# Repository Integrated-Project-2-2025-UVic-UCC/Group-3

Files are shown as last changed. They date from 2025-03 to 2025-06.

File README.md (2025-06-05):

# Autonomous Seeding Quadcopter

This repository contains all the information related to the development of an **autonomous seeding quadcopter**. It also includes everything needed to fully replicate the project.



## 🌱 Motivation

Modern agriculture faces significant challenges, including rising food demand, labor shortages, and the need to improve resource efficiency. Traditional planting methods—whether manual or reliant on heavy machinery—can be costly and inefficient. Labor and initial machinery investments can be very expensive compared to an autonomous drone, which is smaller, cheaper to purchase, and doesn’t require a human operator.

In recent years, automation and technology have started transforming the agricultural sector. Drones have proven useful for crop monitoring, spraying, and data collection. However, **automated drone-based seeding** is still in its early stages of development, presenting a unique opportunity to enhance precision agriculture and improve overall efficiency. This early-stage potential is what inspired us to pursue this project.

## 💪 How to Build

To fully replicate the project, follow these steps:

### 1️⃣ 3D Printing

First, 3D print all the components found in the _SolidWorks parts_ folder. Note that this process may take time, as there are several parts to produce.

### 2️⃣ PCB Building

Once all parts are printed, build the PCB according to the provided electrical schematic. Connect and solder all components, including ESC drivers. It's essential that the MPU6050 module is perfectly centered on the PCB frame.

### 3️⃣ Assembling the Drone

With all parts ready:

**1.** Attach the PCB to the _Bottom body_ (make sure all components are connected before assembly).

**2.** Assemble from bottom to top:

  - Attach the 4 _Leg_ to the _Bottom body_.
  - Attach the 4 _Arm_.
  - Close the structure with the _Upper body_.

At this point, the main structure is complete.

Then:

- Mount the brushless motors to each arm.
- Attach the _Upper battery support_ on top of the frame.

**Hopper Assembly**

1. Attach the servomotor to the _rotative valve cover_, and connect the _rotative valve_ to the servomotor.

2. Insert 4 inserts into the _hopper_.

3. Assemble the full hopper.

4. Attach it to the drone by inserting the two _hinge joints_ into their respective slots.

5. Secure the hopper using a through bolt.

6. Mount the distance sensor onto its support and glue it to the hopper wall.

### 4️⃣ Code Uploading

Once assembly is complete:

- Download the General_BT_Testing folder.
- Upload the program to your ESP32 microcontroller.

### ✅ Completion

If you've followed all the steps — congratulations! 🎉
Your **Autonomous Seeding Quadcopter** is now fully built and ready for testing using a **BLE-compatible device**.

Project by: _**Pau Porcuna, Guillem Català, Albert Huéscar & Álvaro Hernández**_

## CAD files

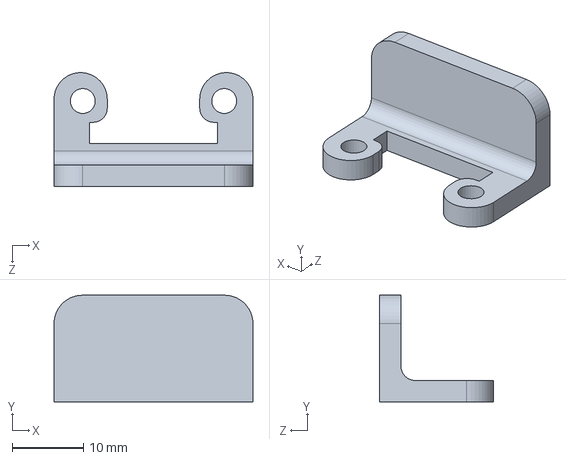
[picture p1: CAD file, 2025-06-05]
src/Structure/SolidWorks files/11 - Distance sensor support.SLDPRT
28.0 x 15.0 x 16.0 mm

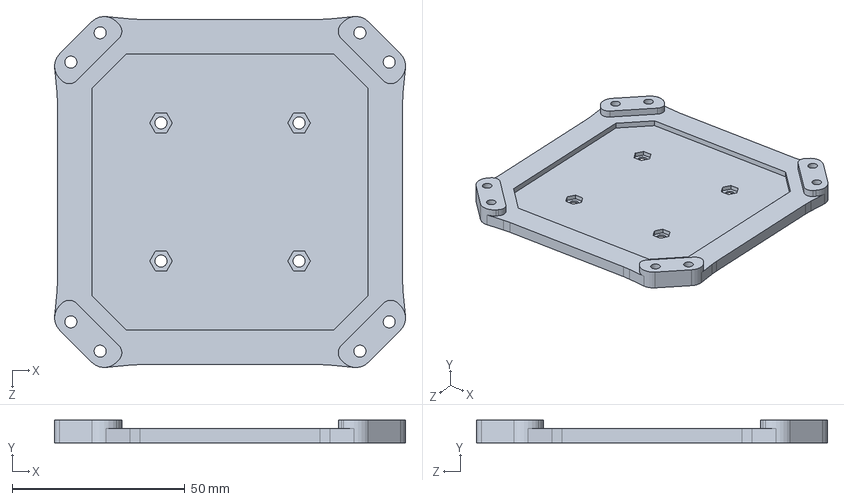
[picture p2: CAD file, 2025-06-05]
src/Structure/SolidWorks files/2 - Upper body.SLDPRT
101.7 x 6.60 x 101.7 mm

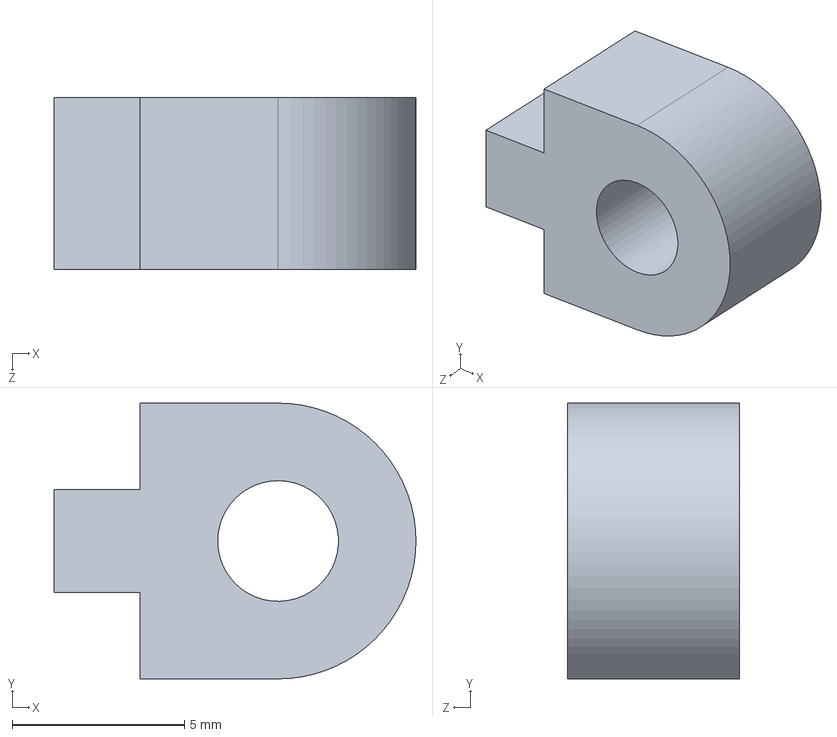
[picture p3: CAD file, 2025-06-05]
src/Structure/SolidWorks files/10 - Hinge joint.SLDPRT
10.5 x 8.00 x 5.00 mm

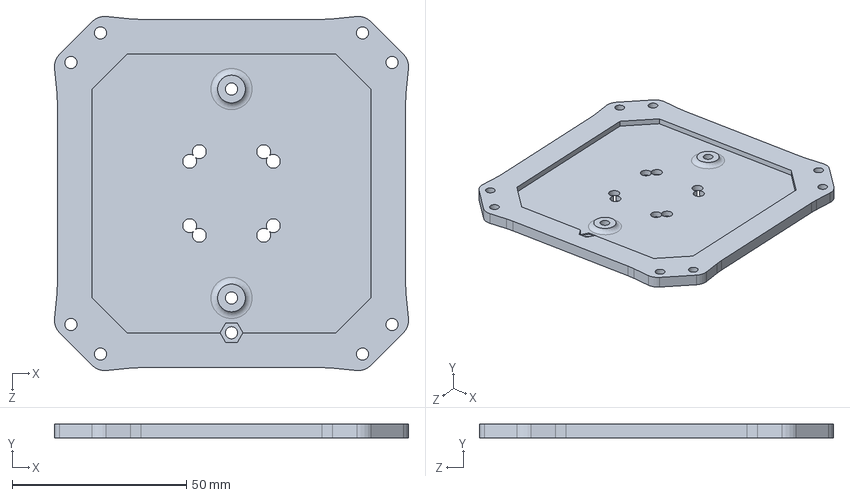
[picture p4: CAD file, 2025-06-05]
src/Structure/SolidWorks files/1 - Bottom body.SLDPRT
101.7 x 4.00 x 101.7 mm

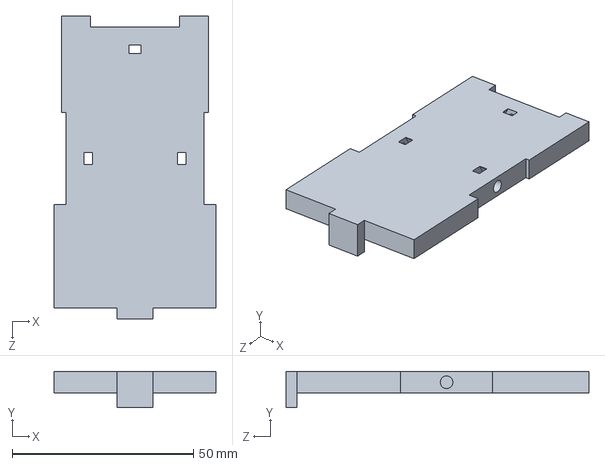
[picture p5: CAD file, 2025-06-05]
src/Structure/SolidWorks files/5 - Upper battery support.SLDPRT
44.6 x 10.0 x 83.6 mm

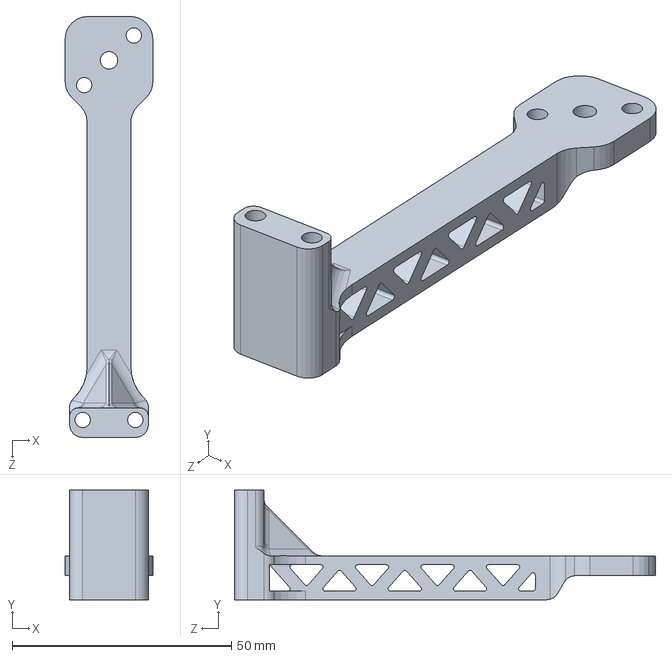
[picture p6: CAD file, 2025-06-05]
src/Structure/SolidWorks files/3 - Arm.SLDPRT
20.0 x 25.0 x 96.0 mm

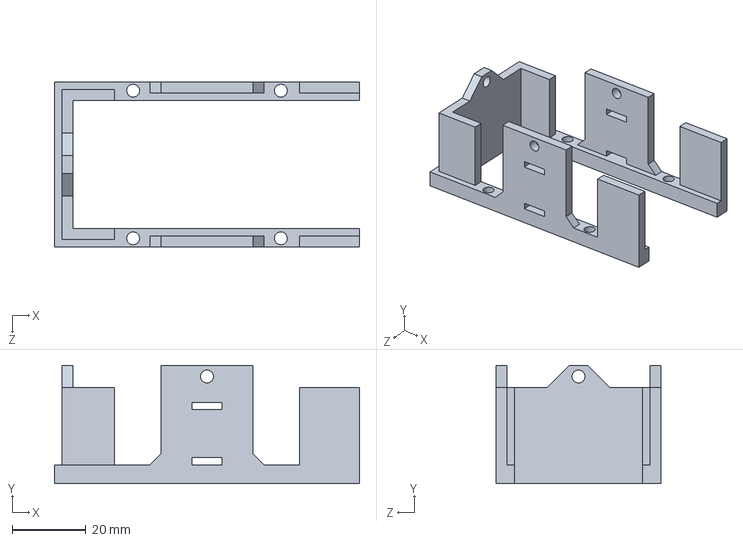
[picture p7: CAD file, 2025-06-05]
src/Structure/SolidWorks files/4 - Bottom battery support.SLDPRT
82.6 x 32.0 x 44.6 mm

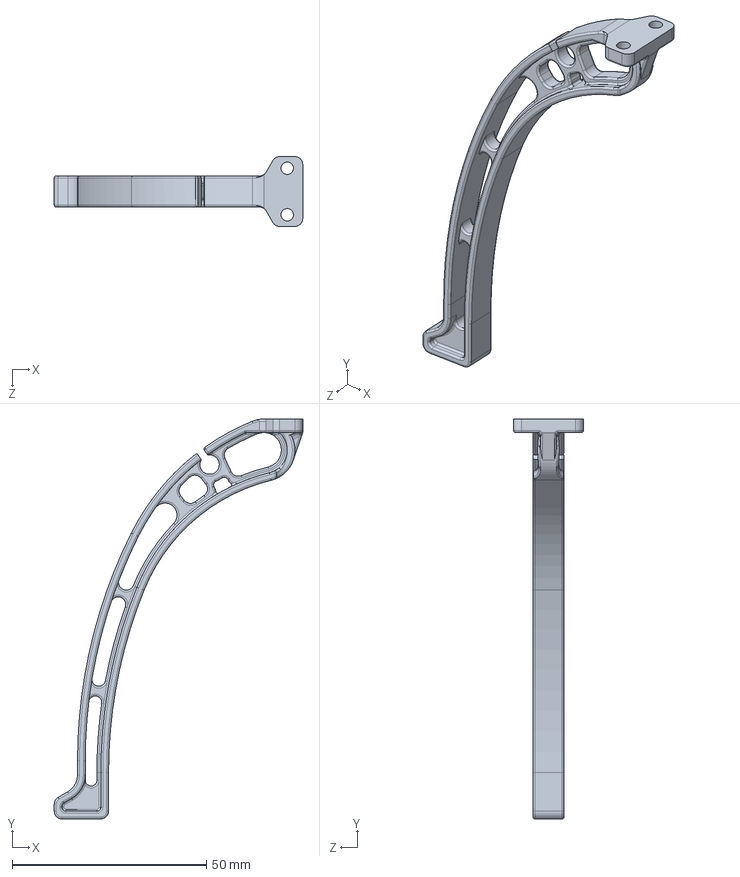
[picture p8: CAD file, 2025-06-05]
src/Structure/SolidWorks files/6 - Leg.SLDPRT
64.0 x 103.0 x 18.0 mm

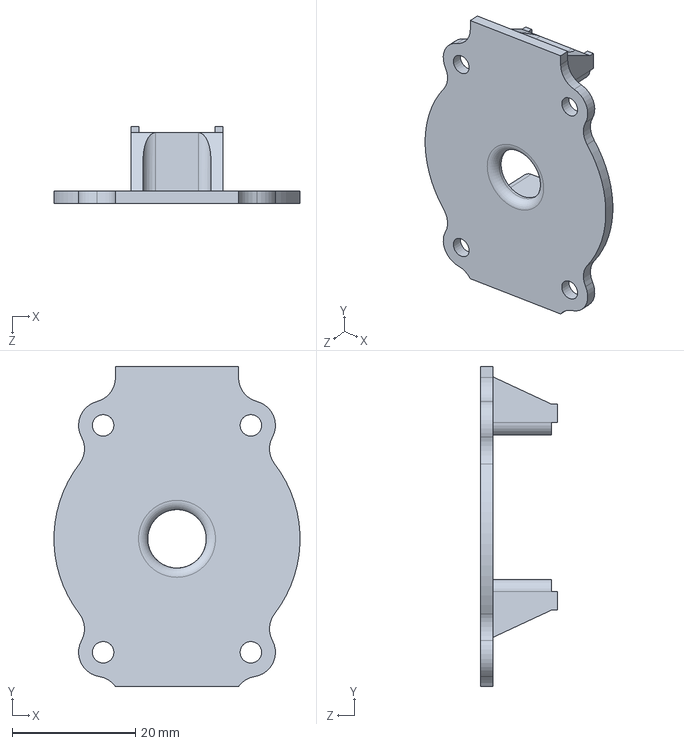
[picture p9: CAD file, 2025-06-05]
src/Structure/SolidWorks files/8 - Rotative valve cover.SLDPRT
40.0 x 52.0 x 12.5 mm

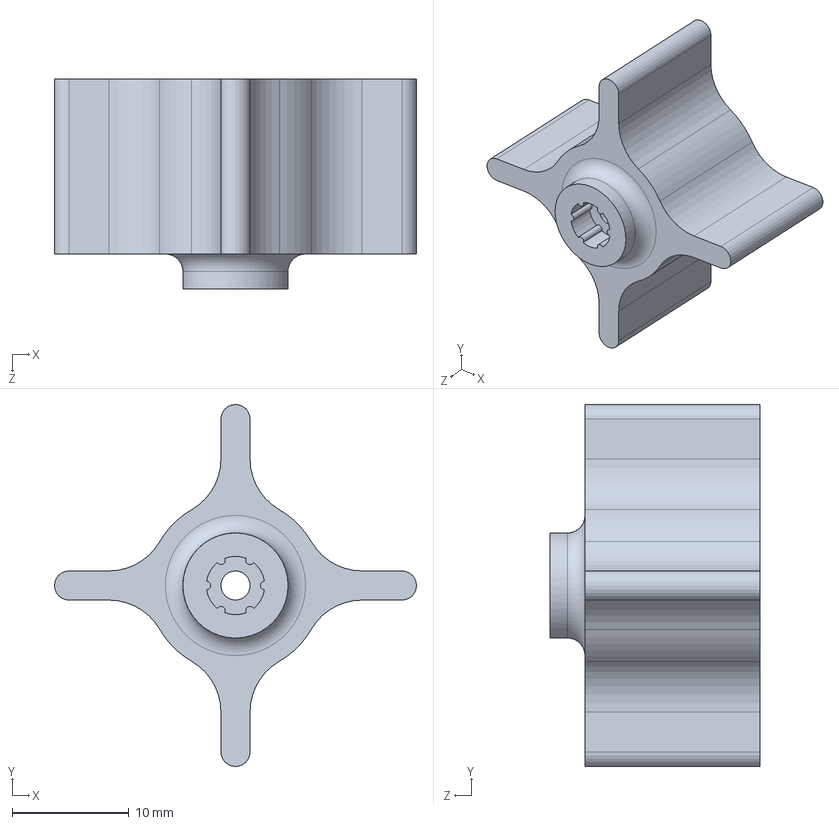
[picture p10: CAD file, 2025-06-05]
src/Structure/SolidWorks files/9 - Rotative valve.SLDPRT
31.0 x 31.0 x 18.0 mm

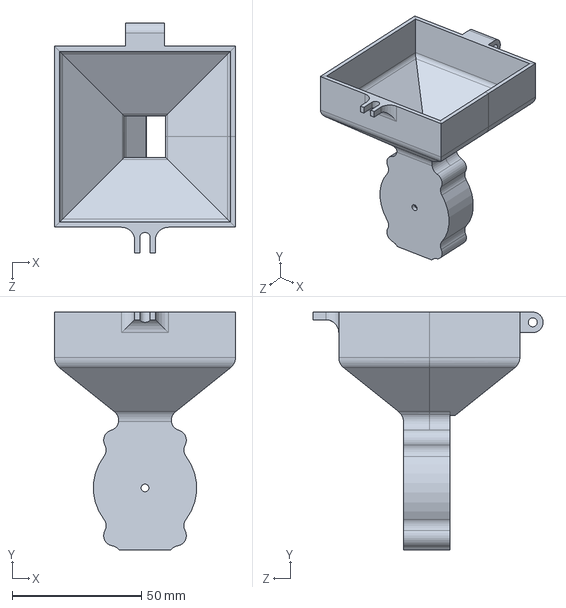
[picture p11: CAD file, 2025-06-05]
src/Structure/SolidWorks files/7 - Hopper + rotative valve enclosure.SLDPRT
70.0 x 92.0 x 89.0 mm

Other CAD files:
src/Structure/SolidWorks drawings/1 - Bottom body.SLDDRW
src/Structure/SolidWorks drawings/10 - Hinge joint.SLDDRW
src/Structure/SolidWorks drawings/11 - Distance sensor support.SLDDRW
src/Structure/SolidWorks drawings/2 - Upper body.SLDDRW
src/Structure/SolidWorks drawings/3 - Arm.SLDDRW
src/Structure/SolidWorks drawings/4 - Bottom battery support.SLDDRW
src/Structure/SolidWorks drawings/5 - Upper battery support.SLDDRW
src/Structure/SolidWorks drawings/6 - Leg.SLDDRW
src/Structure/SolidWorks drawings/7 - Hopper + rotative valve enclosure.SLDDRW
src/Structure/SolidWorks drawings/8 - Rotative valve cover.SLDDRW
src/Structure/SolidWorks drawings/9 - Rotative valve.SLDDRW

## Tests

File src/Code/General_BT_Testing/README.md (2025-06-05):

This files contain the main program to test the Drone via Bluetooth Low Energy. To upload the code to the ESP32 all this files have to be in a folder named "General_BT_Testing"

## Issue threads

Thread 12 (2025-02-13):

3D Doser Design

pauporcuna, 2025-02-13:
3D Model of the structure of the doser

- [ ] Desing of the main frame and mobile components of the doser
- [ ] Desing of the servo motor junction to the mobile components

Closed 2025-03-18.

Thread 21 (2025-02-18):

Stability and height PID control

guillem041, 2025-02-18:

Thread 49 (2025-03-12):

List of received material.

moises-garin, 2025-03-12:
This is the list of material received from UVic. Do not modify this list. If you detect any error, please contact the teachers.

- [ ] 1 x placa ESP32;
- [ ] 1 x mòdul Sensors GY-88 (giroscopi, aceleròmetre, bruixola i  sensor de presió/ temperatura);
- [ ] 1 x Mòdul GPS NEO 6M;
- [ ] 1 x Regulador LM 2596;
- [ ] 1 x bateria de Lipo 2200mAh;
- [ ] 1 x servo petit de 360º;
- [ ] 1 ESC de 18A + 1 motor brushless EMAX 2213;

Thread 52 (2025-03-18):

Soldering the components

Alvar05, 2025-03-18:
Soldering components to be able to make tests:

- [ ] GPS
- [ ] MPU6050 and Barometer
- [ ] ESC cables for testing

Closed 2025-03-25.

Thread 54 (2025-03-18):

Main components basic functions programming

Alvar05, 2025-03-18:
Program the basic functions to control the main sensors and actuators:

- [ ] MPU6050
- [ ] Barometer
- [ ] Brushless Motors

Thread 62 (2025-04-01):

Prototype finishing for stability control programming

Alvar05, 2025-04-01:
Finalization of first prototype to start programming and calibrating stability control modules

Closed 2025-04-25.

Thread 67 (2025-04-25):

1 axis stability PID programming

Alvar05, 2025-04-25:
Finish the code for 1 axis stabilization to start testing it

Closed 2025-05-06.

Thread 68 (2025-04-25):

1 axis stability control testing and PID values adjustment

Alvar05, 2025-04-25:
Testing of the stability control and making the adjustments to the PID constants to optimize the stabilizer

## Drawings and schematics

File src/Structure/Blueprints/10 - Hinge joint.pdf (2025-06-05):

F

4 | 3 | 2 | 1

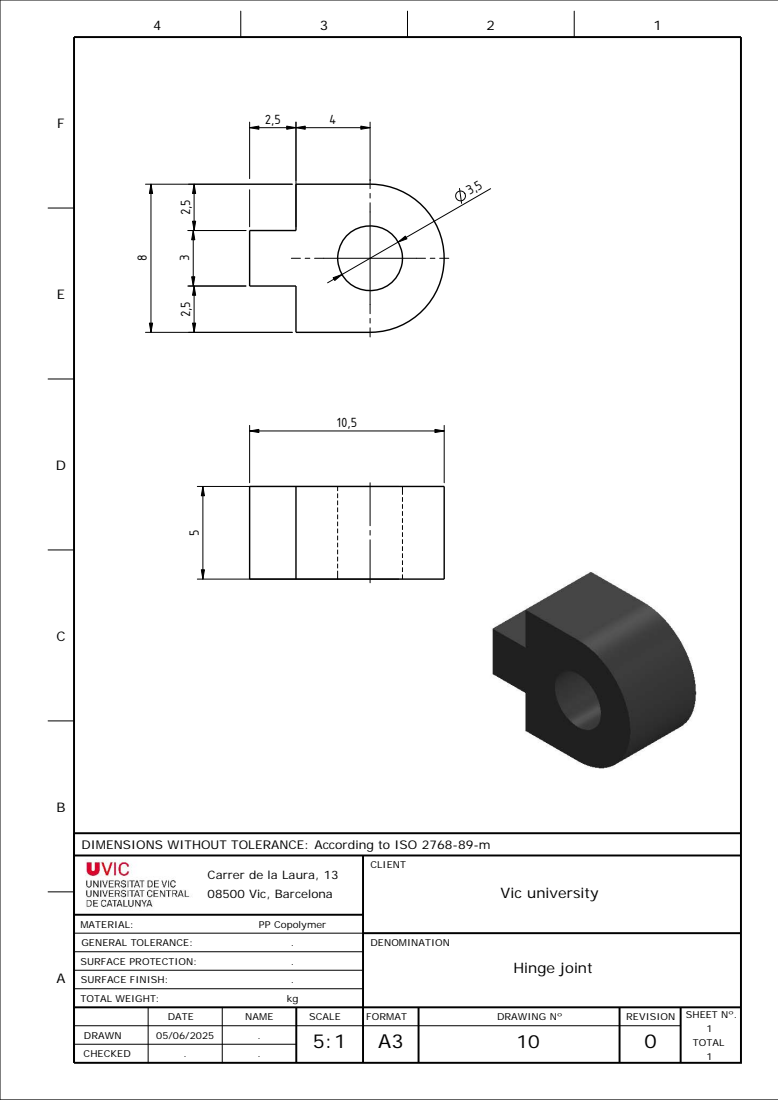
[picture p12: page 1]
REVISION; DENOMINATION; DATE; NAME; DRAWN; CHECKED; SCALE; FORMAT; DRAWING Nº; SHEET Nº.; TOTAL; SURFACE FINISH:; SURFACE PROTECTION:; GENERAL TOLERANCE:; MATERIAL:; TOTAL WEIGHT:; CLIENT; PP Copolymer; Hinge joint; Vic university

DIMENSIONS WITHOUT TOLERANCE: According to ISO 2768-89-m

Carrer de la Laura, 13
08500 Vic, Barcelona

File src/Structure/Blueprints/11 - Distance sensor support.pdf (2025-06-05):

2

F

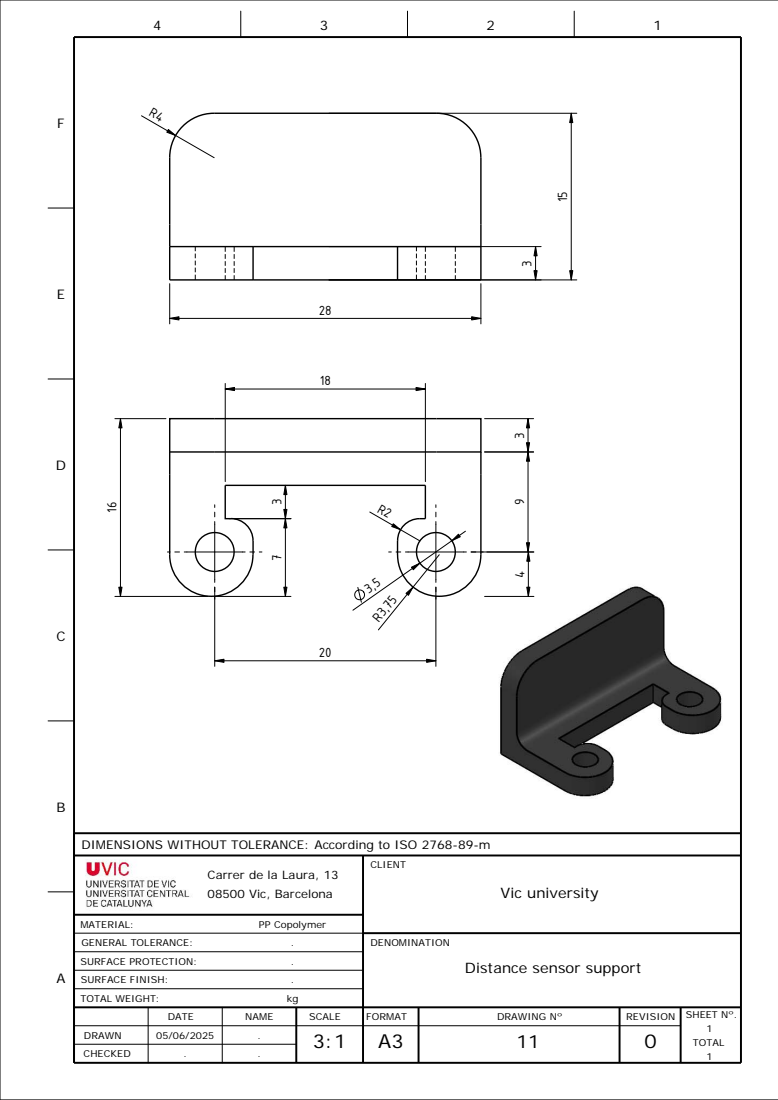
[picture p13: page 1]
DENOMINATION; CLIENT; TOTAL WEIGHT:; SURFACE PROTECTION:; PP Copolymer; GENERAL TOLERANCE:; SURFACE FINISH:; MATERIAL:; Vic university

DIMENSIONS WITHOUT TOLERANCE: According to ISO 2768-89-m

Carrer de la Laura, 13
08500 Vic, Barcelona

Distance sensor support

DATE | NAME | SCALE | FORMAT | DRAWING Nº | REVISION | SHEET Nº. 1 TOTAL 1

DRAWN | | . | 3:1 ⁰⁵/06/2025 | A3 | 11 | 0
CHECKED | . | .

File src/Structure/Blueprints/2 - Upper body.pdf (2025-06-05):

2 | 1

F

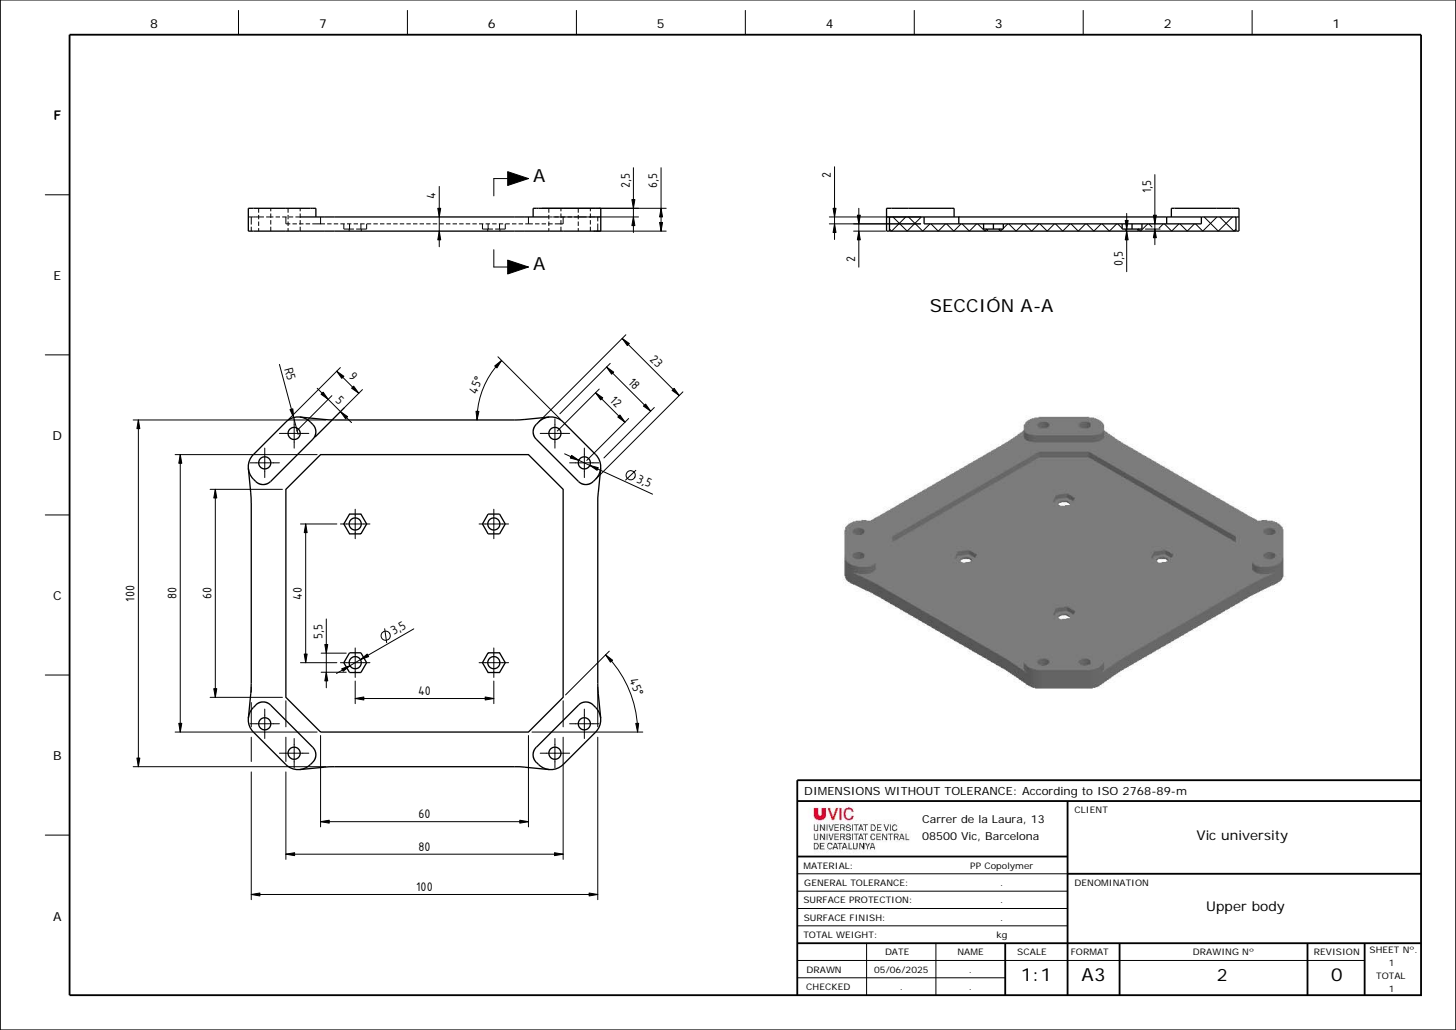
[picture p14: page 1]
PP Copolymer; CLIENT; TOTAL WEIGHT:; MATERIAL:; GENERAL TOLERANCE:; SURFACE PROTECTION:; SURFACE FINISH:; TOTAL; SCALE; FORMAT; DRAWING Nº; SHEET Nº.; CHECKED; DRAWN; DATE; NAME; DENOMINATION; REVISION; Upper body A; Vic university; SECCIÓN A-A

DIMENSIONS WITHOUT TOLERANCE: According to ISO 2768-89-m

Carrer de la Laura, 13
08500 Vic, Barcelona

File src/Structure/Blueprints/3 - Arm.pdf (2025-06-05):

4 | 3 | 2

F

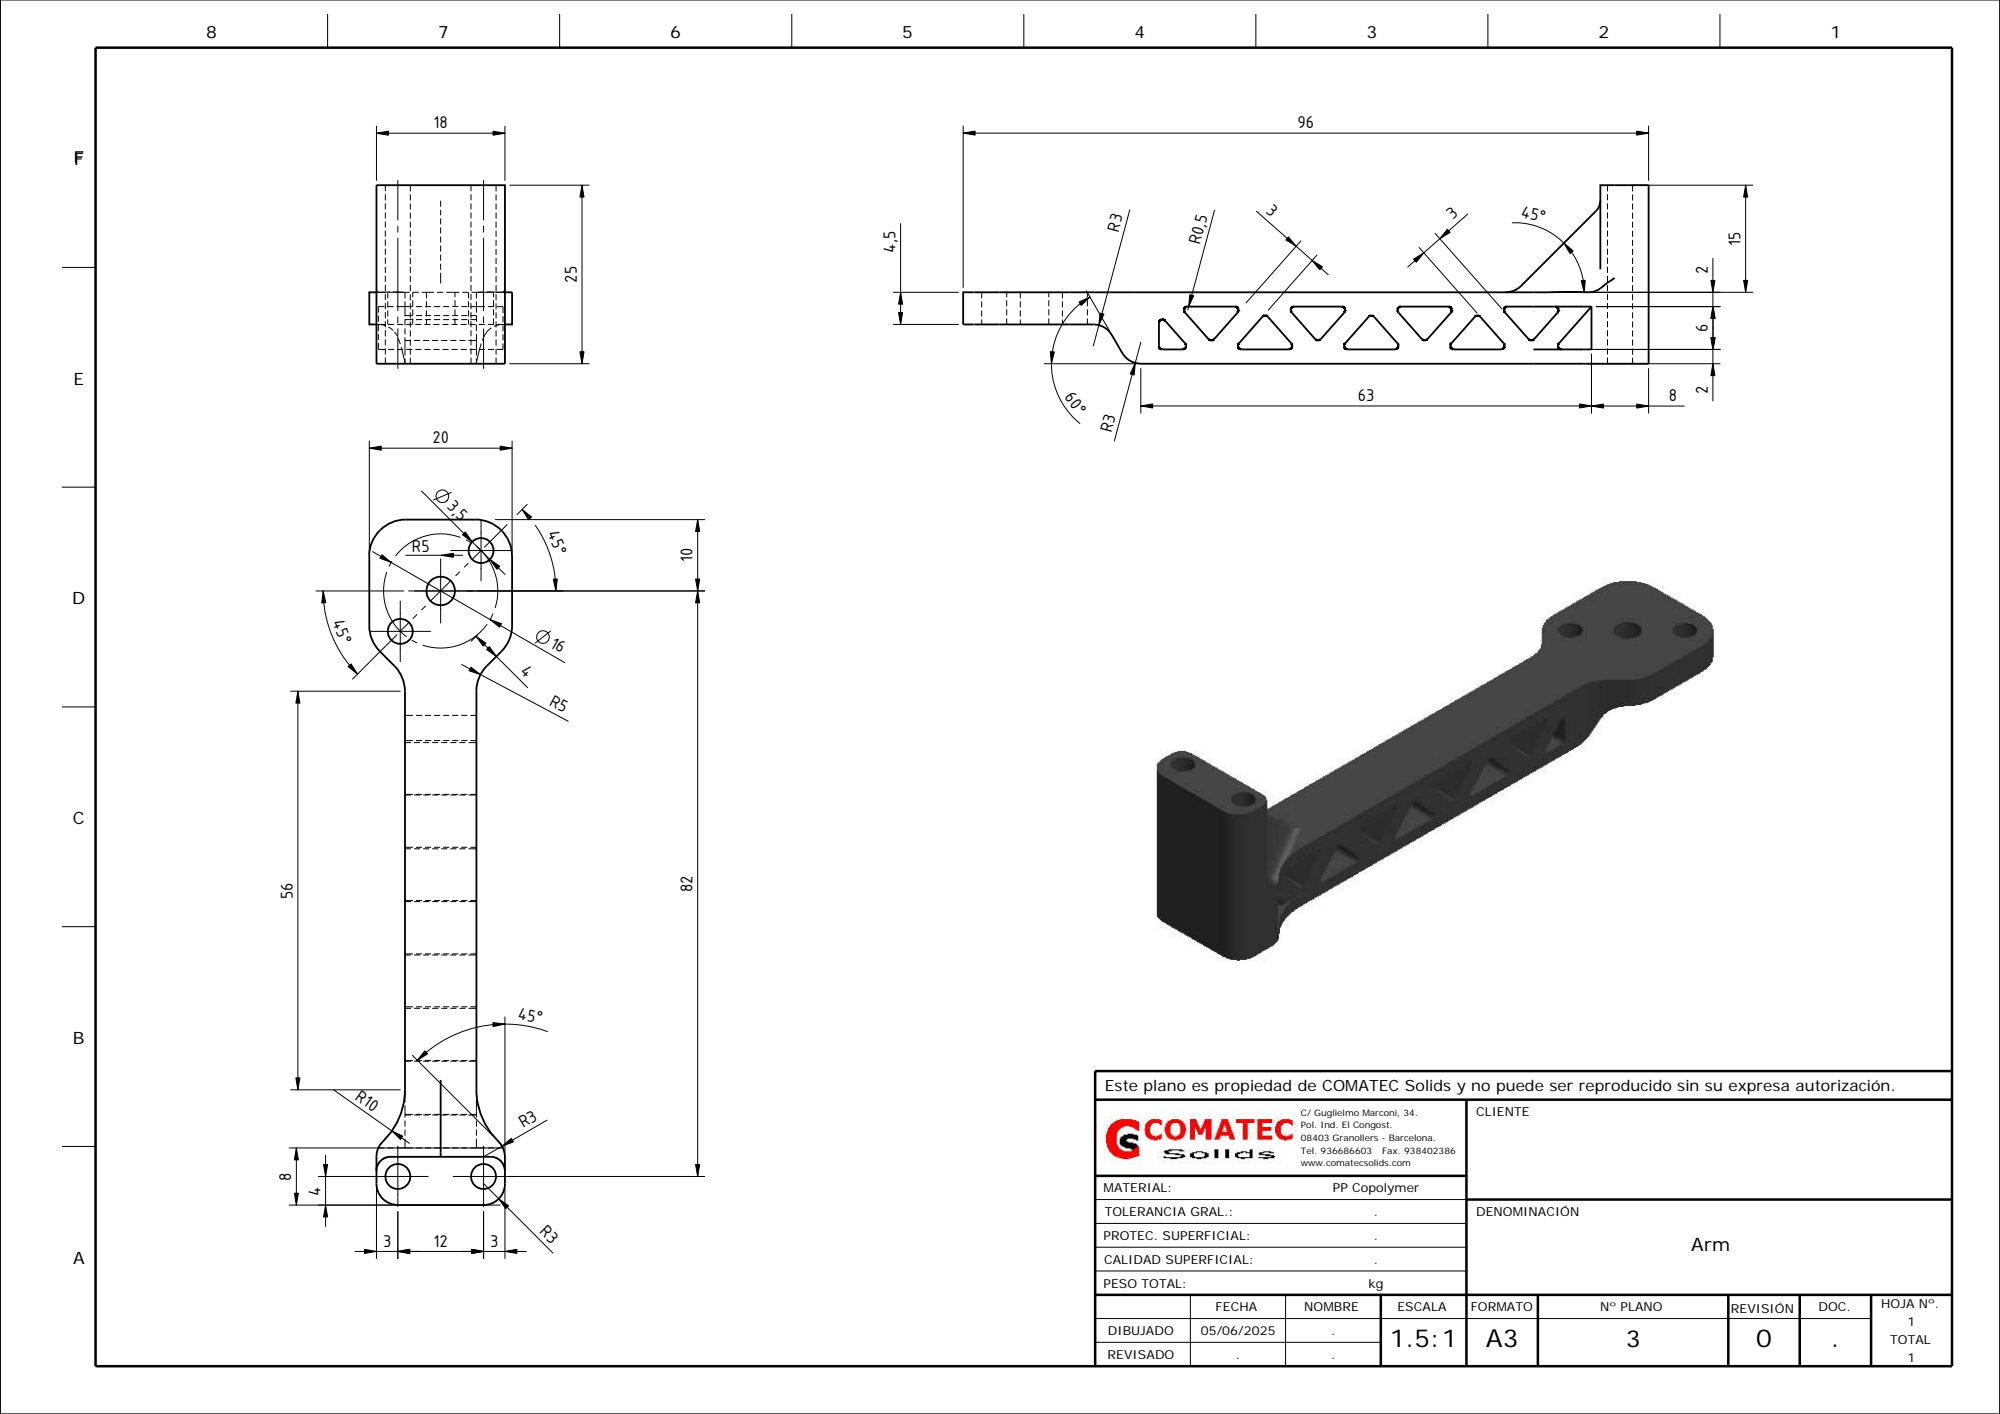
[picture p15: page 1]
CLIENTE; PESO TOTAL:; MATERIAL:; TOLERANCIA GRAL.:; PROTEC. SUPERFICIAL:; CALIDAD SUPERFICIAL:; DENOMINACIÓN; Fax. 938402386; Arm

Este plano es propiedad de COMATEC Solids y no puede ser reproducido sin su expresa autorización.

C/ Guglielmo Marconi, 34.
Pol. Ind. El Congost.
08403 Granollers - Barcelona.
Tel. 936686603
www.comatecsolids.com
PP Copolymer

FECHA | NOMBRE | ESCALA | FORMATO | Nº PLANO | REVISIÓN | DOC. | HOJA Nº. 1 TOTAL 1

DIBUJADO | 05/06/2025 | . | 1.5:1 | A3 | 3 | 0 | .
REVISADO | . | .

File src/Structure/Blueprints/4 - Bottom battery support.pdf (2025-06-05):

7 | 6 | 5 | 4 | 3 | 2 | 1

F

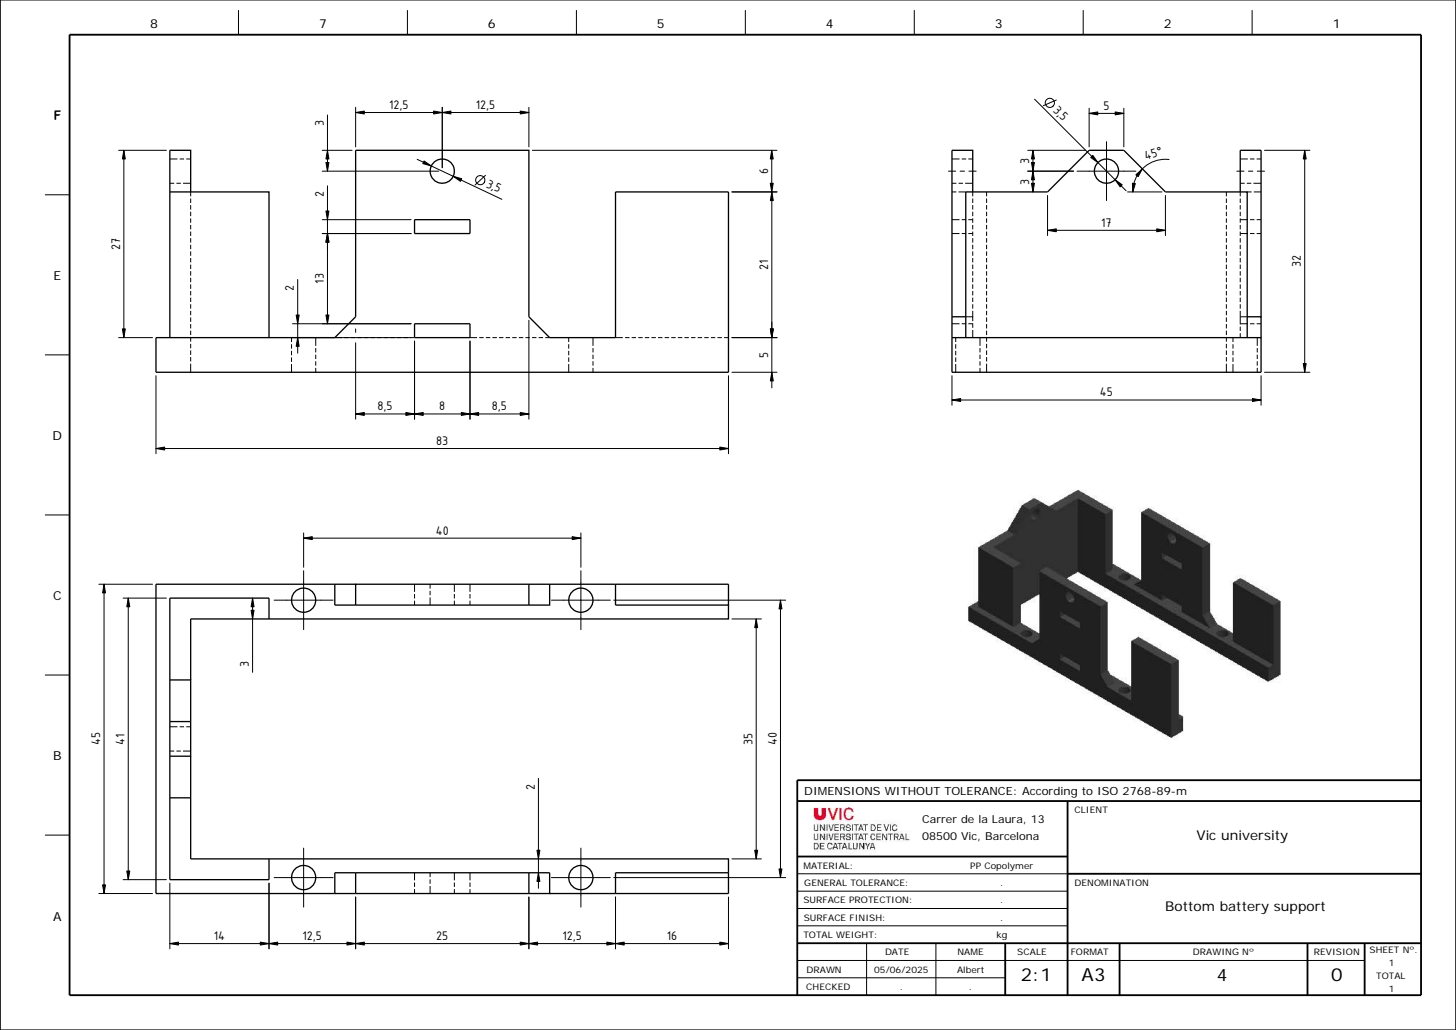
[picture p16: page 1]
DENOMINATION; PP Copolymer; CLIENT; TOTAL WEIGHT:; MATERIAL:; GENERAL TOLERANCE:; SURFACE PROTECTION:; SURFACE FINISH:; Vic university

DIMENSIONS WITHOUT TOLERANCE: According to ISO 2768-89-m

Carrer de la Laura, 13
08500 Vic, Barcelona

Bottom battery support A

DATE | NAME | SCALE | FORMAT | DRAWING Nº | REVISION | SHEET Nº. 1 TOTAL 1

DRAWN | 05/06/2025 | Albert | 2:1 | A3 | 4 | 0
CHECKED | . | .

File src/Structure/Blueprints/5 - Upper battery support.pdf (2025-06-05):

4 | 3 | 2

1

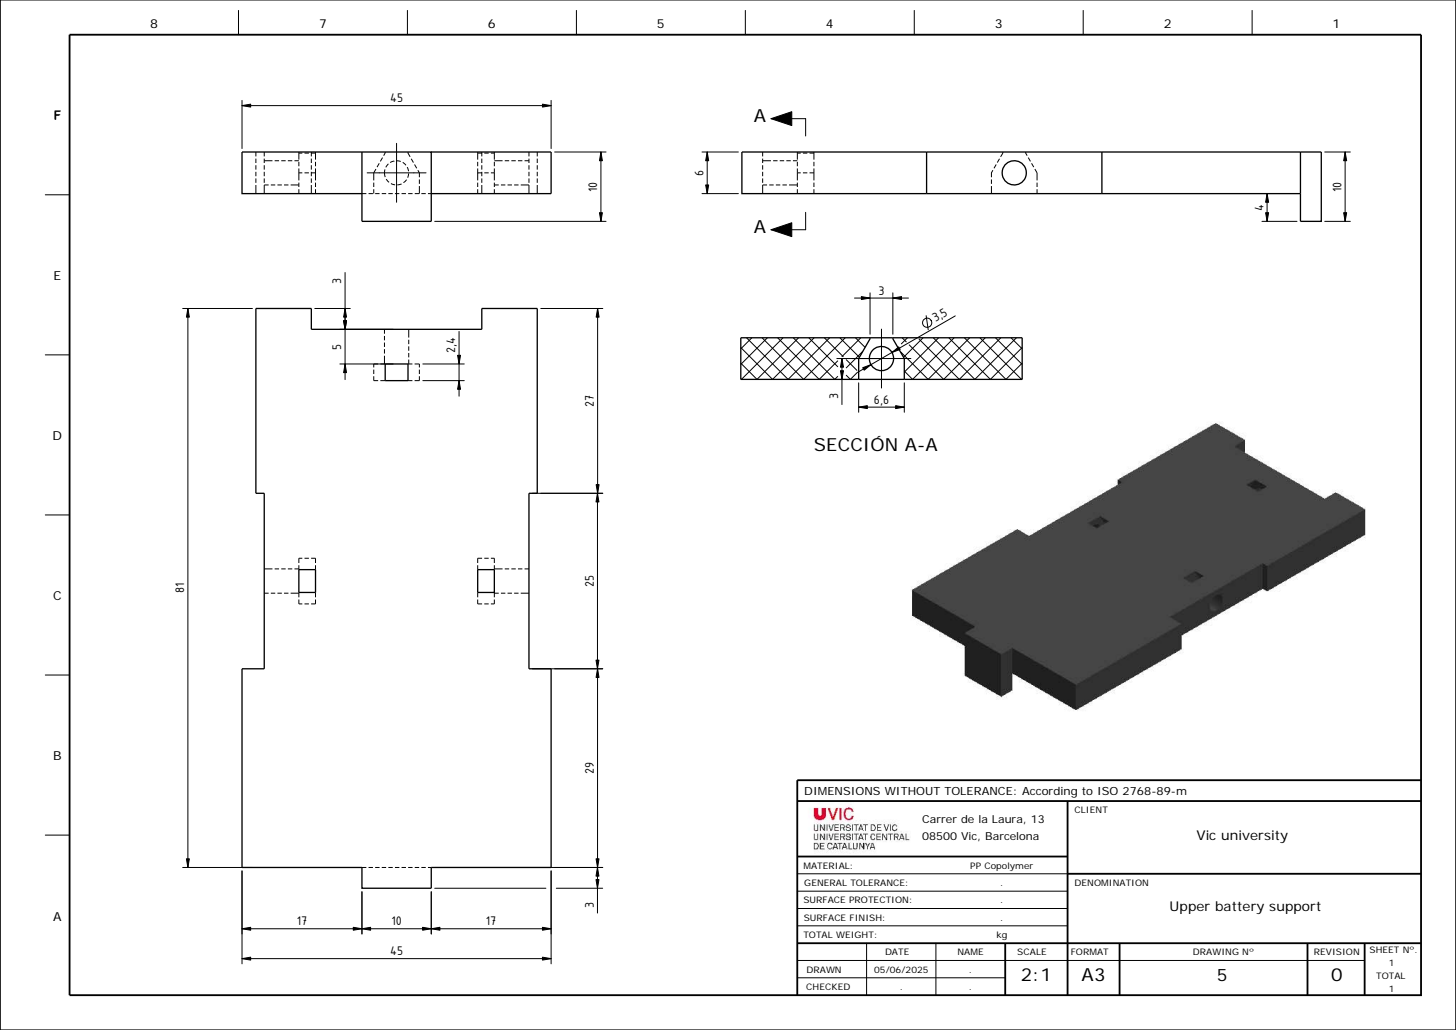
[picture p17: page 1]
DENOMINATION; PP Copolymer; CLIENT; TOTAL WEIGHT:; MATERIAL:; GENERAL TOLERANCE:; SURFACE PROTECTION:; SURFACE FINISH:; TOTAL; SCALE; FORMAT; DRAWING Nº; SHEET Nº.; CHECKED; DRAWN; DATE; NAME; REVISION 0; Vic university; SECCIÓN A-A

DIMENSIONS WITHOUT TOLERANCE: According to ISO 2768-89-m

Carrer de la Laura, 13
08500 Vic, Barcelona

Upper battery support A

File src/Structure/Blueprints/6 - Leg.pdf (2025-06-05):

2 | 1

F

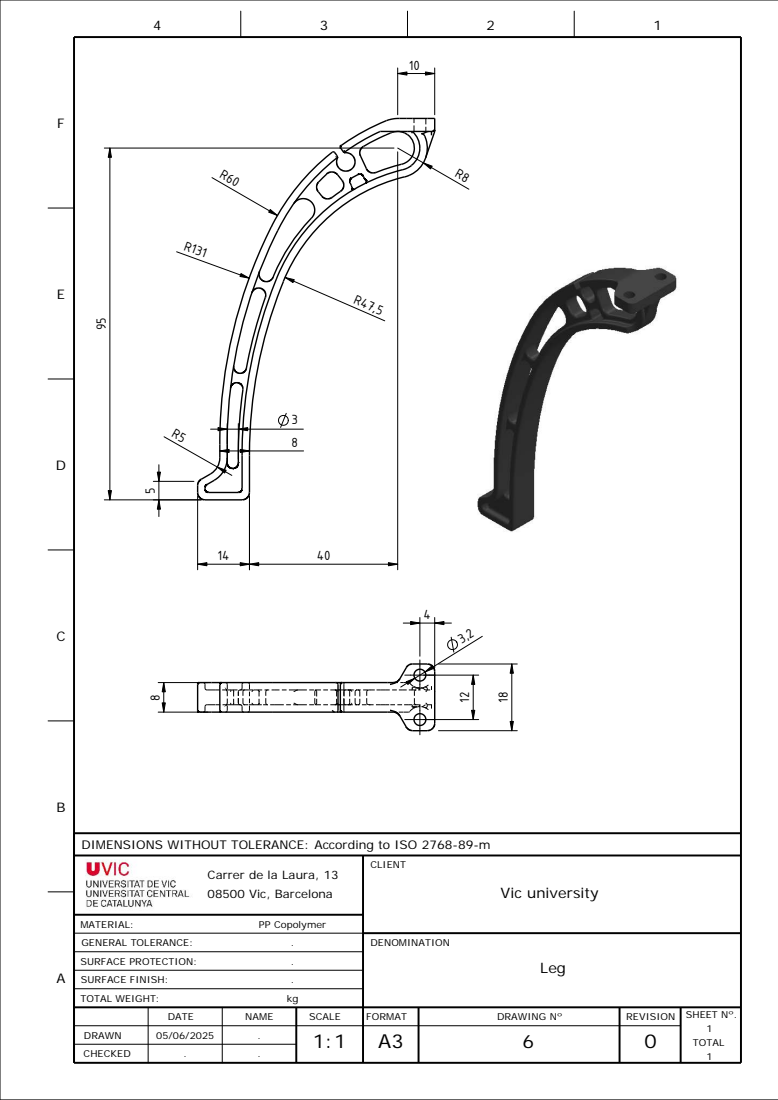
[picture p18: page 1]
DENOMINATION; SURFACE FINISH:; SURFACE PROTECTION:; GENERAL TOLERANCE:; MATERIAL:; TOTAL WEIGHT:; CLIENT; PP Copolymer; Vic university; Leg A

DIMENSIONS WITHOUT TOLERANCE: According to ISO 2768-89-m

Carrer de la Laura, 13
08500 Vic, Barcelona

DATE | NAME | SCALE | FORMAT | DRAWING Nº | REVISION | SHEET Nº. TOTAL 1

DRAWN | | . | 1:1 . | A3 | 6 | 0 | 1 05/06/2025

CHECKED | | .

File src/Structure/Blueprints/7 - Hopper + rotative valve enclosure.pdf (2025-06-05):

1

3

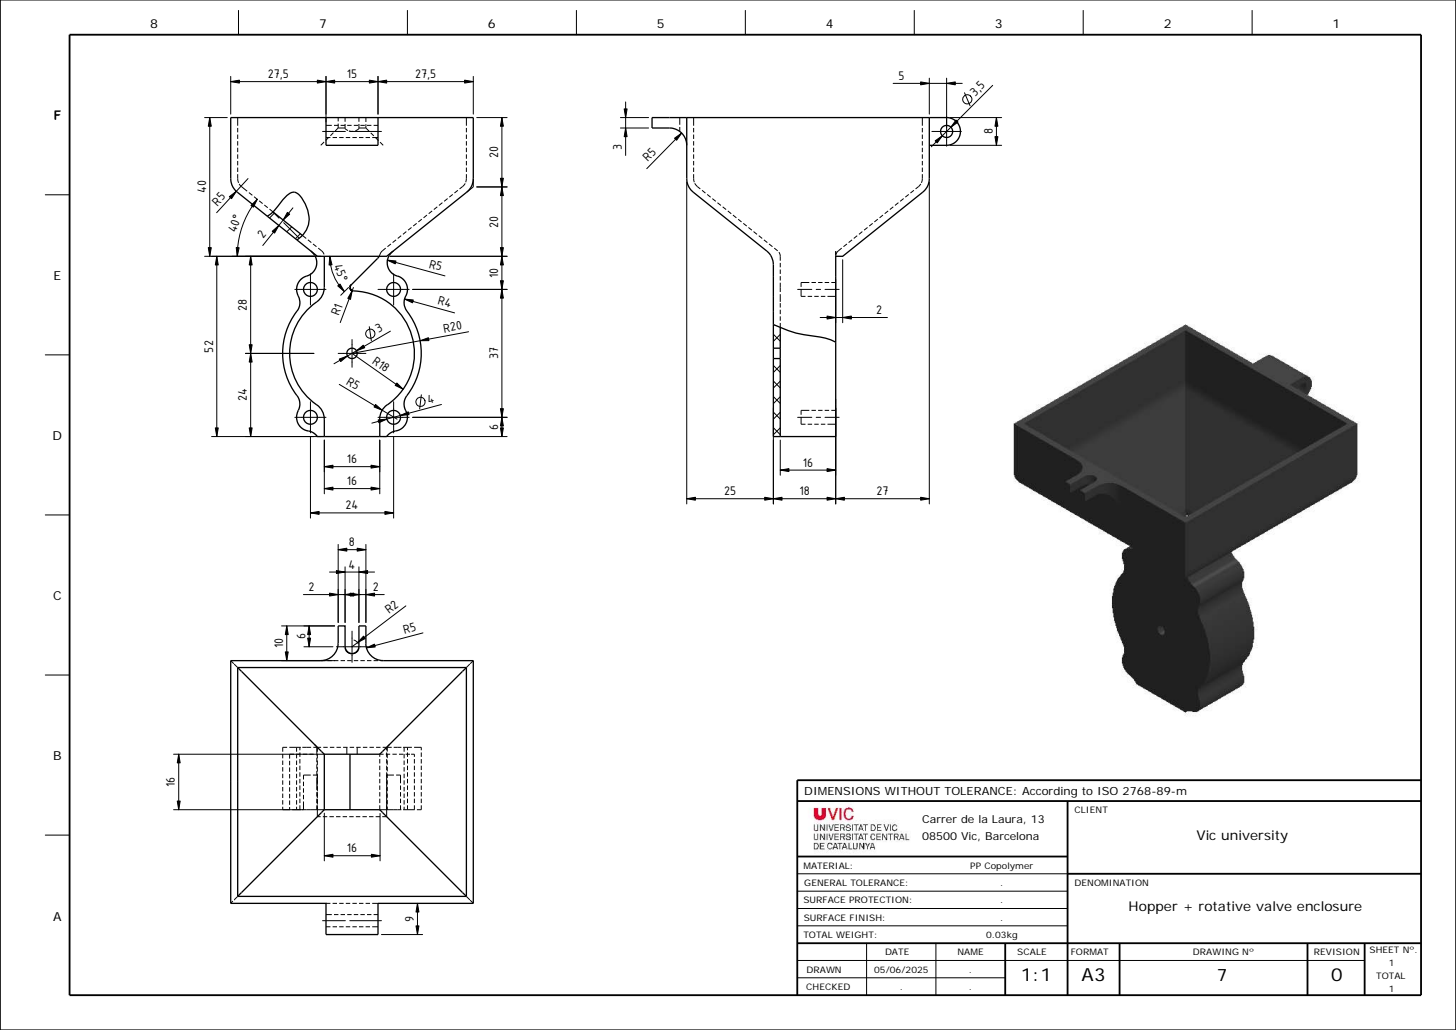
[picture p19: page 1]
DENOMINATION; CLIENT; SURFACE PROTECTION:; PP Copolymer; TOTAL WEIGHT:; MATERIAL:; GENERAL TOLERANCE:; SURFACE FINISH:; Vic university

DIMENSIONS WITHOUT TOLERANCE: According to ISO 2768-89-m

Carrer de la Laura, 13
08500 Vic, Barcelona

Hopper + rotative valve enclosure

DATE | NAME | SCALE | FORMAT | DRAWING Nº | REVISION | SHEET Nº. 1 TOTAL 1

DRAWN | | . | 1:1 | A3 ⁰⁵/06/2025 | 7 | 0
CHECKED | . | .

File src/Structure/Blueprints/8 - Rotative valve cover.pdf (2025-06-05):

2

1

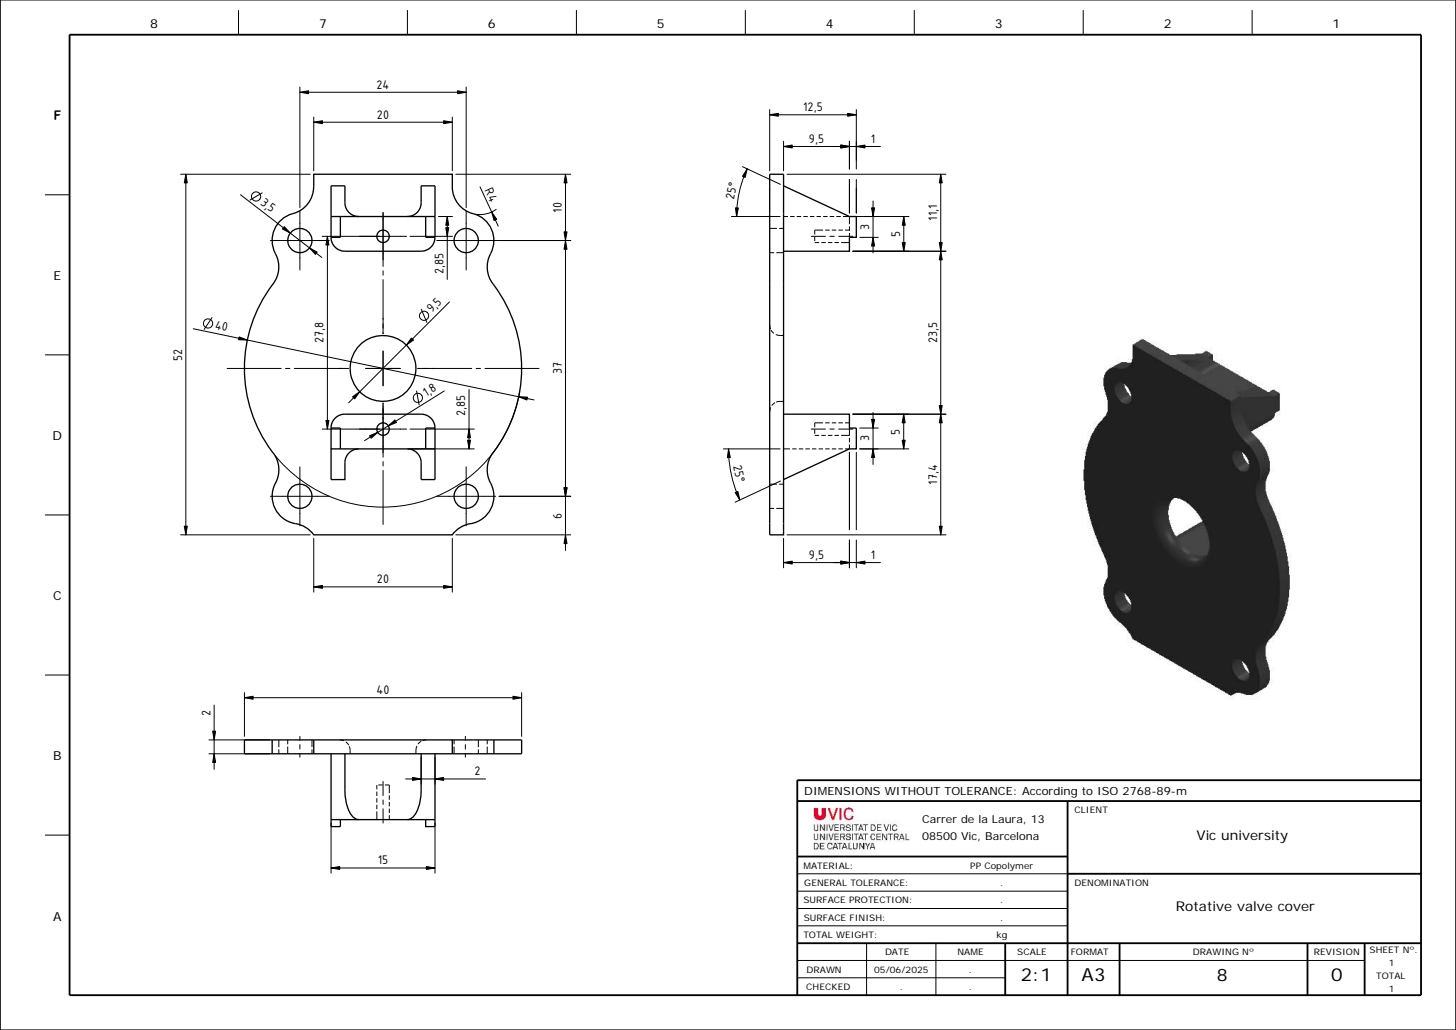
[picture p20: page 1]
DENOMINATION; PP Copolymer; CLIENT; SURFACE FINISH:; TOTAL WEIGHT:; MATERIAL:; GENERAL TOLERANCE:; SURFACE PROTECTION:; Vic university

DIMENSIONS WITHOUT TOLERANCE: According to ISO 2768-89-m

Carrer de la Laura, 13
08500 Vic, Barcelona

Rotative valve cover

DATE | NAME | SCALE | FORMAT | DRAWING Nº | REVISION | SHEET Nº. 1 TOTAL 1

DRAWN | 05/06/2025 | . | 2:1 | A3 | 8 | 0
CHECKED | . | .

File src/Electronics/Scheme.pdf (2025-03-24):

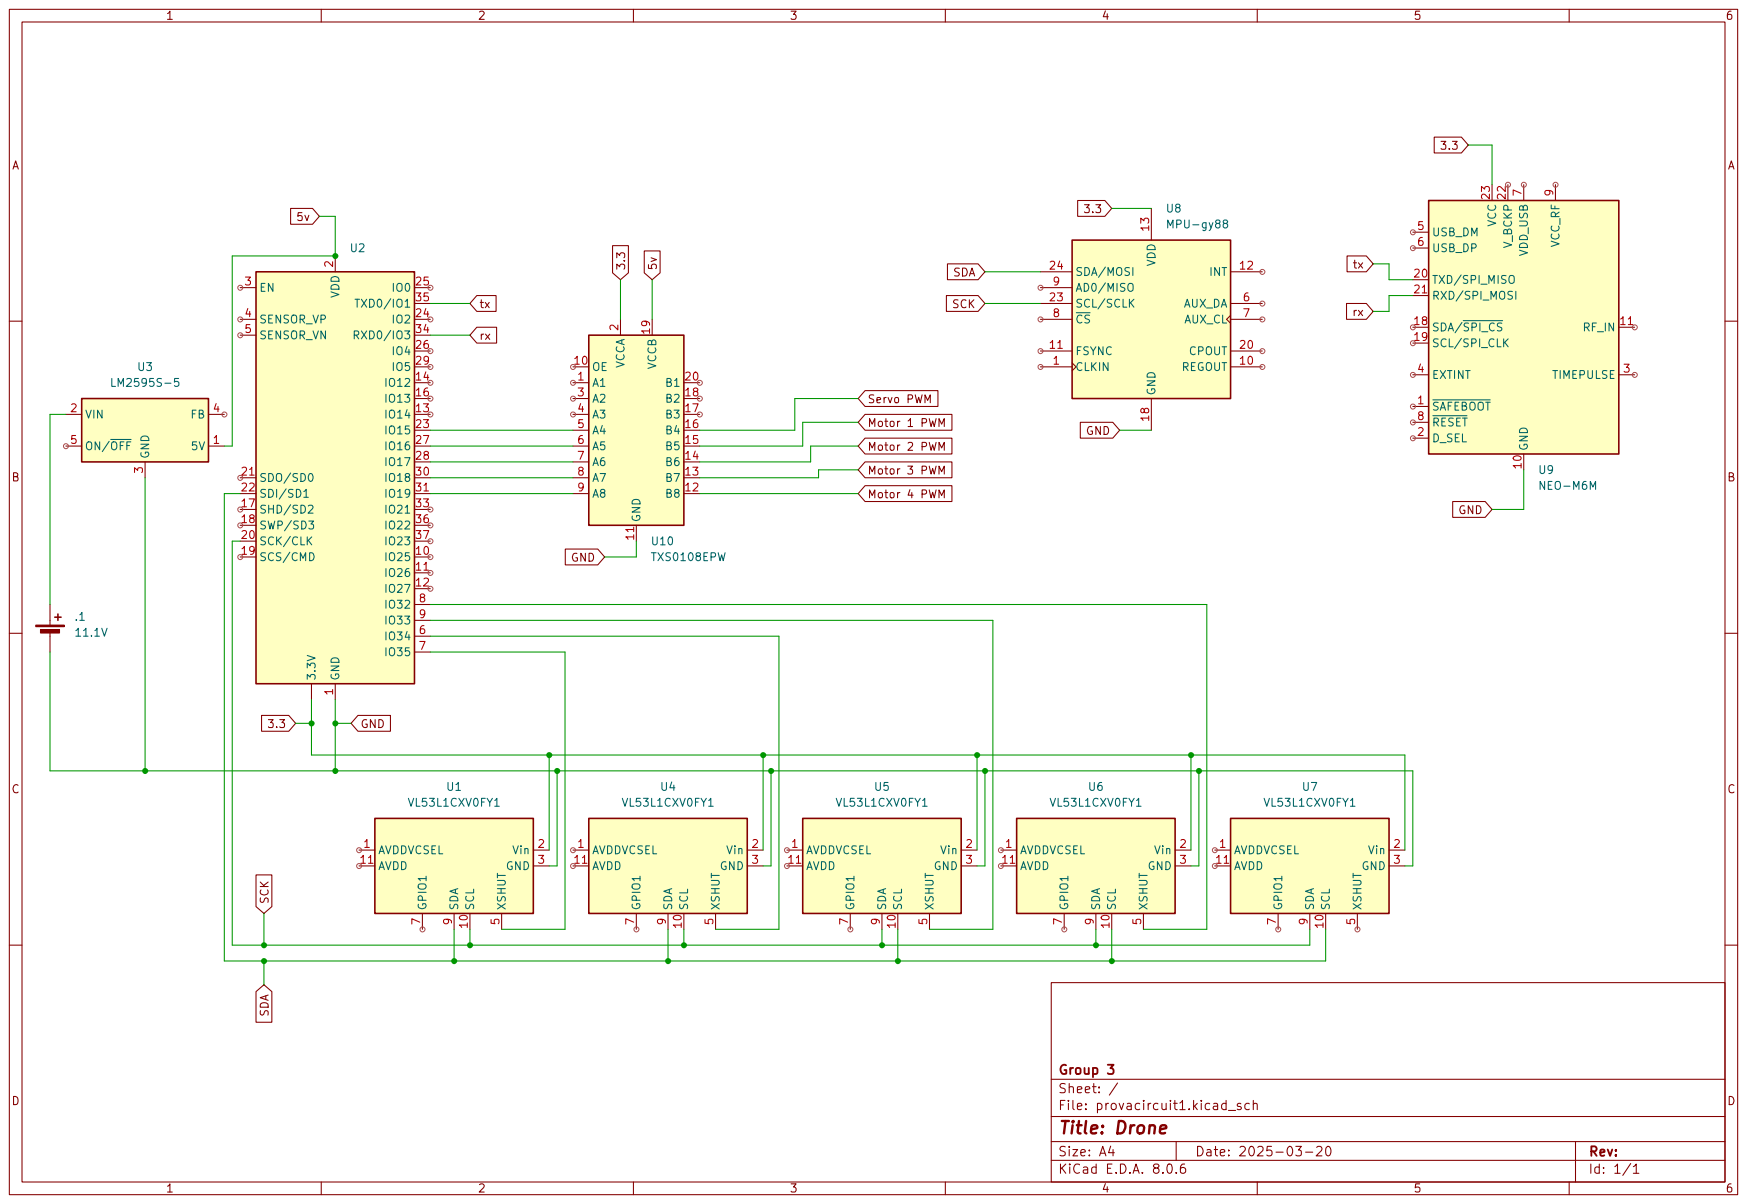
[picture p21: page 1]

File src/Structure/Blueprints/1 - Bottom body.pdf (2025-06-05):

3 | 2 | 1

F

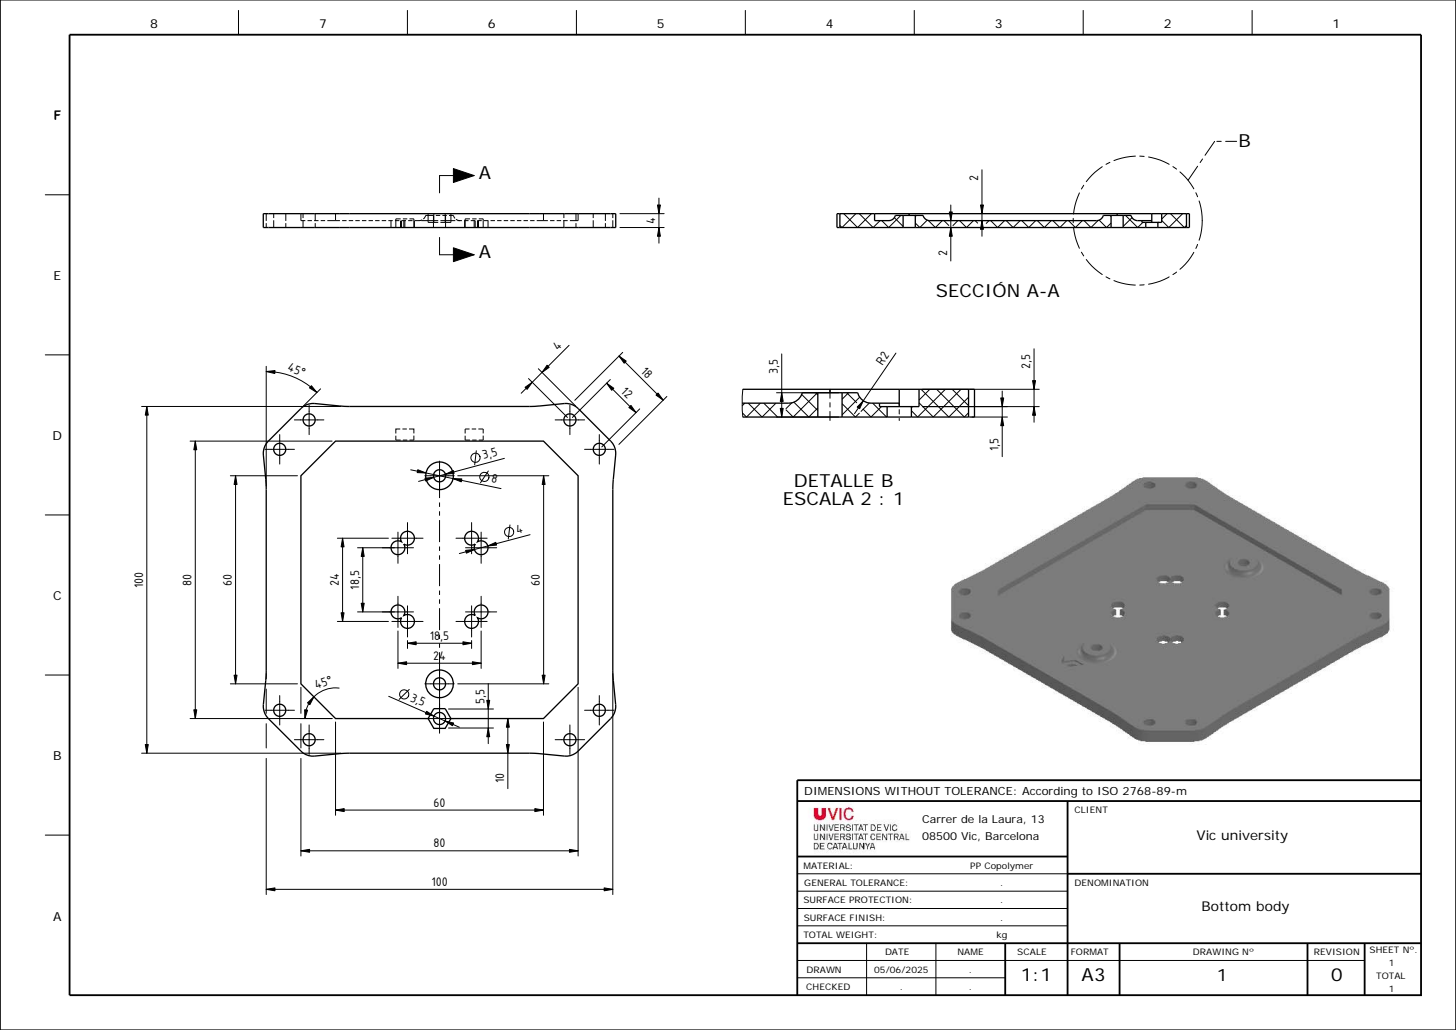
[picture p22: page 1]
DENOMINATION; PP Copolymer; CLIENT; TOTAL WEIGHT:; MATERIAL:; GENERAL TOLERANCE:; SURFACE PROTECTION:; SURFACE FINISH:; TOTAL; SCALE; FORMAT; DRAWING Nº; SHEET Nº.; CHECKED; DRAWN; DATE; NAME; REVISION; Bottom body A; Vic university; SECCIÓN A-A; DETALLE B ESCALA 2 : 1

DIMENSIONS WITHOUT TOLERANCE: According to ISO 2768-89-m

Carrer de la Laura, 13
08500 Vic, Barcelona

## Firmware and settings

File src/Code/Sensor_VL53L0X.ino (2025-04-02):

#include <VL53L0X.h> 
#include <Wire.h>

VL53L0X sensor; 

int startTime = millis(); 
int mInterval = 100; 

void setup() {
    Serial.begin(9600);
    
    Wire.begin(); 
    Wire.setClock(400000); 

    sensor.setTimeout(500); 
    
    if (!sensor.init()) {
        Serial.println("VL53L0X no responde, verifica el cableado.");
    } else {
        sensor.setSignalRateLimit(0.1);
        sensor.setVcselPulsePeriod(VL53L0X::VcselPeriodPreRange, 18);
        sensor.setVcselPulsePeriod(VL53L0X::VcselPeriodFinalRange, 14);
        sensor.setMeasurementTimingBudget(40000); 
        sensor.startContinuous(50);
    }   
}

void loop() {
    if ((millis() - startTime) > mInterval) {
        int distancia = sensor.readRangeContinuousMillimeters();
        
        // Detecta errores en la medición
        if (sensor.timeoutOccurred()) {
            Serial.println("Error: Tiempo de espera excedido");
        } else {
            Serial.print("Distancia: ");
            Serial.print(distancia);
            Serial.println(" mm");
        }
        
        startTime = millis();
    }
}

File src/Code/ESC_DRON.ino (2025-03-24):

#include<Servo.h>

Servo ESC;

int vel = 1000; // Amplitud minima de pulso para tu ESC

void setup() {
  ESC.attach(9); // Pin en el que funciona
  //Activar el ESC
  ESC.writeMicroseconds(1000); //1000 = 1ms
  //Cambia el 1000 anterior por 2000 si
  //tu ESC se activa con un pulso de 2ms
  delay(5000); //Esperar 5 segundos para hacer la activacion
  Serial.begin(9600);
  Serial.setTimeout(10);
}
void loop() {
 if(Serial.available() >= 1)
  {
    vel = Serial.parseInt(); //Leer un entero por serial
    if(vel != 0)
    {
      ESC.writeMicroseconds(vel); //Generar un pulso con el numero recibido
    }
  }
}

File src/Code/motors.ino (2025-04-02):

#include <ESP32Servo.h>
#define motorA 12  // Front-left motor PWM pin
#define motorB 13  // Front-right motor PWM pin
#define motorC 14  // Rear-right motor PWM pin
#define motorD 15  // Rear-left motor PWM pin
Servo FL;
Servo FR;
Servo RR;
Servo RL;

void motorSetup() {
  FL.setPeriodHertz(50);
  FR.setPeriodHertz(50);
  RR.setPeriodHertz(50);
  RL.setPeriodHertz(50);
  FL.attach(motorA, 1000, 2000);
  FR.attach(motorB, 1000, 2000);
  RR.attach(motorC, 1000, 2000);
  RL.attach(motorD, 1000, 2000);
  FL.writeMicroseconds(1000);  // Inititates the ESCs to min value
  FR.writeMicroseconds(1000);
  RR.writeMicroseconds(1000);
  RL.writeMicroseconds(1000);
}


void motorStart(String motorSelect, byte power) {  // Motor select --> A:Front-Left B:Front-Right C:Rear-Right D:Rear-Left   Power --> (0-100)
  int usMap = map(power, 0, 100, 1000, 2000);
  for (uint8_t i = 0; i < motorSelect.length(); i++) {
    if (motorSelect.charAt(i) == 'A') FL.writeMicroseconds(usMap);
    else if (motorSelect.charAt(i) == 'B') FR.writeMicroseconds(usMap);
    else if (motorSelect.charAt(i) == 'C') RR.writeMicroseconds(usMap);
    else if (motorSelect.charAt(i) == 'D') RL.writeMicroseconds(usMap);
  }
}
